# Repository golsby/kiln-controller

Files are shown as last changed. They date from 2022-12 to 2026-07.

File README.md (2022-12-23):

Kiln Controller
==========

Turns a Raspberry Pi into an inexpensive, web-enabled kiln controller.

## Features

  * easy to create new kiln schedules and edit / modify existing schedules
  * no limit to runtime - fire for days if you want
  * view status from multiple devices at once - computer, tablet etc
  * real-time firing cost estimate
  * NIST-linearized conversion for accurate K type thermocouple readings
  * supports PID parameters you tune to your kiln
  * monitors temperature in kiln after schedule has ended
  * api for starting and stopping at any point in a schedule
  * supports MAX31856 and MAX31855 thermocouple boards
  * support for K, J, N, R, S, T, E, or B type thermocouples
  * accurate simulation
  * support for shifting schedule when kiln cannot heat quickly enough
  * prevents integral wind-up when temperatures not near the set point
  * automatic restarts if there is a power outage or other event

**Run Kiln Schedule**

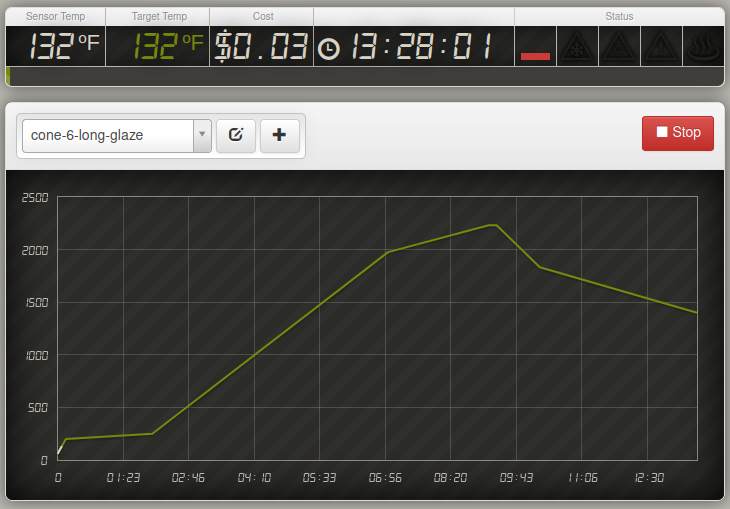
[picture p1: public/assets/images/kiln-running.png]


**Edit Kiln Schedule**



## Hardware

### Parts

| Image | Hardware | Description |
| ---| --- | --- |
|  | [Raspberry Pi](https://www.adafruit.com/category/105) | Virtually any Raspberry Pi will work since only a few GPIO pins are being used. |
|  | [MAX31855](https://www.adafruit.com/product/269) or [MAX31856](https://www.adafruit.com/product/3263) | Thermocouple breakout board |
|  | [K-Type Thermocouple](https://www.auberins.com/index.php?main_page=product_info&cPath=20_3&products_id=39) | Invest in a heavy duty, ceramic, k-type thermocouple designed for kilns |
|  | Breadboard | breadboard, ribbon cable, connector for pi's gpio pins & connecting wires |
|  | Solid State Relay | Zero crossing, make sure it can handle the max current of your kiln. Even if the kiln is 220V you can buy a single [3 Phase SSR](https://www.auberins.com/index.php?main_page=product_info&cPath=2_30&products_id=331). It's like having 3 SSRs in one.  Relays this big always require a heat sink. |
|  | Electric Kiln | There are many old electric kilns on the market that don't have digital controls. You can pick one up on the used market cheaply.  This controller will work with 110V or 220V (pick a proper SSR). My kiln is a Skutt KS-1018. |

### Schematic

The pi has three gpio pins connected to the MAX31855 chip. D0 is configured as an input and CS and CLK are outputs. The signal that controls the solid state relay starts as a gpio output which drives a transistor acting as a switch in front of it. This transistor provides 5V and plenty of current to control the ssr. Since only four gpio pins are in use, any pi can be used for this project. See the [config](https://github.com/jbruce12000/kiln-controller/blob/master/config.py) file for gpio pin configuration.

My controller plugs into the wall, and the kiln plugs into the controller. 

**WARNING** This project involves high voltages and high currents. Please make sure that anything you build conforms to local electrical codes and aligns with industry best practices.



*Note: I tried to power my ssr directly using a gpio pin, but it did not work. My ssr required 25ma to switch and rpi's gpio could only provide 16ma. YMMV.*

## Software 

### Raspberry PI OS

Download [Raspberry PI OS](https://www.raspberrypi.org/software/). Use Rasberry PI Imaging tool to install the OS on an SD card. Boot the OS, open a terminal and...

    $ sudo apt-get update
    $ sudo apt-get dist-upgrade
    $ sudo apt-get install python3-dev python3-virtualenv libevent-dev virtualenv
    $ git clone https://github.com/jbruce12000/kiln-controller
    $ cd kiln-controller
    $ virtualenv -p python3 venv
    $ source venv/bin/activate
    $ export CFLAGS=-fcommon
    $ pip3 install --upgrade setuptools
    $ pip3 install greenlet bottle gevent gevent-websocket

*Note: The above steps work on ubuntu if you prefer*

### Raspberry PI deployment

If you're done playing around with simulations and want to deploy the code on a Raspberry PI to control a kiln, you'll need to do this in addition to the stuff listed above:

    $ cd kiln-controller
    $ virtualenv -p python3 venv
    $ source venv/bin/activate
    $ export CFLAGS=-fcommon
    $ pip3 install -r requirements.txt

## Configuration

All parameters are defined in config.py, review/change to your mind's content.

You should change, test, and verify PID parameters in config.py.  Here is a [PID Tuning Guide](https://github.com/jbruce12000/kiln-controller/blob/master/docs/pid_tuning.md). There is also an [autotuner](https://github.com/jbruce12000/kiln-controller/blob/master/docs/ziegler_tuning.md). Be patient with tuning. No tuning is perfect across a wide temperature range.

You may want to change the configuration parameter **sensor_time_wait**. It's the duty cycle for the entire system.  It's set to two seconds by default which means that a decision is made every 2s about whether to turn on relay[s] and for how long. If you use mechanical relays, you may want to increase this. At 2s, my SSR switches 11,000 times in 13 hours.

## Usage

### Server Startup

    $ source venv/bin/activate; ./kiln-controller.py

### Autostart Server onBoot
If you want the server to autostart on boot, run the following command:

    $ /home/pi/kiln-controller/start-on-boot

### Client Access

Click http://127.0.0.1:8081 for local development or the IP
of your PI and the port defined in config.py (default 8081).

### Simulation

In config.py, set **simulate=True**. Start the server and select a profile and click Start. Simulations run at near real time.

### Watcher

If you're busy and do not want to sit around watching the web interface for problems, there is a watcher.py script which you can run on any machine in your local network or even on the raspberry pi which will watch the kiln-controller process to make sure it is running a schedule, and staying within a pre-defined temperature range. When things go bad, it sends messages to a slack channel you define. I have alerts set on my android phone for that specific slack channel. Here are detailed [instructions](https://github.com/jbruce12000/kiln-controller/blob/master/docs/watcher.md).

## License

This program is free software: you can redistribute it and/or modify
it under the terms of the GNU General Public License as published by
the Free Software Foundation, either version 3 of the License, or
(at your option) any later version.

This program is distributed in the hope that it will be useful,
but WITHOUT ANY WARRANTY; without even the implied warranty of
MERCHANTABILITY or FITNESS FOR A PARTICULAR PURPOSE.  See the
GNU General Public License for more details.

You should have received a copy of the GNU General Public License
along with this program.  If not, see <http://www.gnu.org/licenses/>.

## Support & Contact

Please use the issue tracker for project related issues.
If you're having trouble with hardware, I did too.  Here is a [troubleshooting guide](https://github.com/jbruce12000/kiln-controller/blob/master/docs/troubleshooting.md) I created for testing RPi gpio pins.

## Origin
This project was originally forked from https://github.com/apollo-ng/picoReflow but has diverged a large amount.

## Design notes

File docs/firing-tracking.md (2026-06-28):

# Firing Tracking & History — Design

Status: **in progress** (branch `firing-tracking`; round 2 on `merge-timeline`)
Author: Brian Gillespie
Last updated: 2026-06-28

## Round 2 (branch `merge-timeline`)

Brings the history detail to the **live, in-progress firing** and makes photos first-class:

- **Live unified detail.** `/status` now broadcasts `firing_id` (`ovenWatcher`); while a
  firing runs the dashboard shows the same detail view as history (annotated canvas graph +
  live event timeline + editable notes) for that firing, polling `/api/firings/<id>` every
  ~5 s. The flot graph is used only for idle profile preview/editing.
- **Segments behind Edit.** The live segment editor no longer auto-shows; an "Edit schedule"
  toggle reveals it (table-driven: tap a row to edit its target/hold via `/control`).
- **Photos as moments.** Photos taken during a firing carry the capture `runtime` (sent on
  upload), so they appear as 📷 markers on the graph and as their own rows in the timeline at
  the exact time slice (single source of truth in `metadata.photos`, not separate events).
  Click a marker/thumbnail → lightbox with the full image and an editable per-photo **note**.
- **Layout.** Timeline and notes stack vertically; the timeline grows to show every event
  (no inner scroll).
- **Printable report.** `report.html?id=<id>` renders a clean, paper-styled full report
  (graph, entire timeline, notes, all photos + captions); a Report link sits on the detail.

Backend: photo entries are `{file, runtime, note}`; `PATCH /api/firings/:id/photos/:name`
sets the note. **Writes to the active firing go through the live `FiringRecorder`** (it owns
`record.json` in memory) so the watcher's flushes can't clobber notes/photos edited mid-firing.

## Goal

Give the kiln controller a durable concept of a **firing**: capture every run as a
self-contained record (the planned schedule, the actual temperature log, a timeline of
what happened, and human-authored notes/results), and surface past firings in the
dashboard for review and annotation.

Today the system has **no concept of a completed firing**. Profiles persist as JSON;
everything else is ephemeral — the live time-series lives only in `ovenWatcher.last_log`
in memory and is wiped on Stop or client reconnect. There is a standing `FIXME` at
`lib/ovenWatcher.py:104` — *"need to save runs of schedules in near-real-time."* This
feature answers it.

## Scope & non-goals

In scope:
- A persistent, self-contained **firing record** per run, captured in near-real-time.
- A **controller identity** (GUID + human name) established from day one.
- A **History** view in the dashboard (list + detail with planned-vs-actual graph,
  event annotations, and editable metadata).
- A one-time **importer** that backfills past firings from `process.log` + existing CSVs.

Explicitly out of scope (deferred to the future **cloud/remote-access** project):
- Remote access from outside the LAN, auth, multi-tenant accounts.
- Syncing multiple controllers under one account.
- Cloud storage / offload of records or photos.

This design is **cloud-forward**, not cloud-coupled: records are self-contained bundles
and all access goes through a clean local `/api/firings` REST surface, so the future AWS
layer is a proxy in front of this — not a rewrite.

## Controller identity

Established now because it is cheap to add and expensive to retrofit once firing records
reference it.

- Stored in a **gitignored `controller.json`** at the repo root, alongside `resume.json`
  and `state.json` — per-device, survives `git pull`, never committed (so every tenant's
  device is globally unique).
- Auto-created on first startup if absent:
  ```json
  { "id": "f47ac10b-58cc-4372-a567-0e02b2c3d479", "name": "Studio Kiln" }
  ```
  - `id` — a UUIDv4. Globally unique across all tenants/devices. Immutable.
  - `name` — human-friendly label shown on the dashboard. Editable. Defaults to the
    machine hostname on first creation.
- Exposed read-only via the existing `/config` websocket (`controller_id`,
  `controller_name`). Renamed via a new `/api` action `set_controller_name`.
- Every firing record embeds `controller_id` so records remain attributable after they
  are someday synced/merged across controllers.

## The firing record — a self-contained bundle

One directory per firing under `storage/firings/`, parallel to `storage/profiles/`:

```
storage/firings/<id>/
  record.json      # summary + embedded profile snapshot + user metadata
  samples.ndjson   # actual firing log: one get_state() dict per line, appended live
  events.ndjson    # discrete event timeline, appended live
  photos/          # user-attached before/after images
```

`<id>` is the UTC start timestamp in a filesystem-safe form, e.g.
`2026-06-22T21-23-13Z`. A directory (not a single file) because a firing accrues
heterogeneous content over its life: the curve while it runs, then notes and photos added
days later.

### `record.json`

```jsonc
{
  "id": "2026-06-22T21-23-13Z",
  "controller_id": "f47ac10b-...",          // attribution for future multi-controller
  "schema_version": 1,

  // ---- summary (auto-computed; refreshed on segment change + finalize) ----
  "status": "completed",                     // running | completed | aborted | error
  "started_at": "2026-06-22T21:23:13Z",
  "ended_at":   "2026-06-23T05:01:40Z",
  "duration_s": 27507,
  "max_temp": 1465.0,
  "peak_target": 1466.0,
  "total_cost": 3.49,
  "currency_type": "$",
  "temp_scale": "f",
  "segment_count": 6,

  // ---- the PLAN: profile snapshot as run (embedded, never a reference) ----
  "profile": { "name": "...", "type": "profile", "data": [[0,100],...], "rth": [...] },

  // ---- user metadata (editable forever after) ----
  "metadata": {
    "title": "",
    "tags": [],                 // free-form: "full-fuse", "test", "oceanside-thin"
    "fields": {},               // arbitrary user key→value; domain-agnostic
    "outcome": {
      "rating": null,           // 1–5
      "summary": "",
      "defects": [],            // free-form chips: "devit", "bubbles", "cracked"
      "went_well": "",
      "went_wrong": ""
    },
    "photos": []                // refs into photos/, with optional before/after label
  }
}
```

Design choices:
- **Embed the profile, don't reference it.** Profiles get edited and deleted; a record
  that stores only `"profile": "cone06-fast"` is worthless once that profile changes. The
  bundle carries the schedule *as actually run*.
- **Metadata is generic.** A fixed core where it helps the UI render controls (rating,
  defects), and open-ended `tags`/`fields` so it fits any craft without domain lock-in.

### `samples.ndjson` — the actual firing log

One slim line per sample, appended as `ovenWatcher` produces it. NDJSON because it is
append-only and crash-safe: if the Pi loses power mid-firing, the record up to that instant
survives. Only the fields needed to graph the firing and to reconstruct an idealized curve
from it are persisted:

```json
{"runtime": 350.0, "temperature": 146.86, "target": 147.6, "heat": 1.0, "totaltime": 7800.0}
```

Everything constant or derived — profile name, `cost`, `kwh_rate`, `currency_type`, the
upcoming-`segments` array, `pidstats`, `resume_*` — lives once in `record.json` rather than
being duplicated on every line. `state` is omitted too: samples are only captured while the
oven is `RUNNING`, so run-state changes are recorded as discrete events in `events.ndjson`. Values are lightly rounded (temps to 0.01°, below
thermocouple resolution) to drop precision-noise. This keeps a long firing's log small.

Note this is a deliberate split from the live feed: the `/status` websocket still carries
the **full** `get_state()` (the live dashboard needs `segments`, `pidstats` for the tuning
view, etc.); only the persisted file is slimmed. The UI downsamples stored samples for
display via a `?resolution=` query param.

### `events.ndjson` — what actually happened

A low-volume stream of discrete events, each `{ts, type, runtime, detail}`, appended live.
These turn a temperature curve into a *narrative*. Example line:

```json
{"ts": "2026-06-27T21:02:04Z", "type": "segment_target_edit", "runtime": 638.0, "detail": {"segment": 2, "old": 1826.0, "new": 900.0}}
```

The event types (vocabulary lives in `firingStore.EV_*`) and where each is emitted:

| Event type | Emitted by | When |
|---|---|---|
| `started` | watcher | a fresh bundle opens on the first RUNNING sample |
| `completed` / `aborted` / `error` | watcher | the run leaves RUNNING (terminal status inferred from oven state) |
| `hold` / `hold_release` | `oven.set_manual_hold` | manual hold engaged / released (detail: `setpoint`) |
| `advance` | `oven.advance_segment` | user skipped to the next segment (detail: `from_segment`, `to_segment`) |
| `segment_target_edit` / `segment_hold_edit` | `oven.set_segment_target` / `set_segment_hold` | runtime edit (detail: `segment`, `old`, `new`) |
| `segment_transition` | watcher | segment/phase changed between samples (RAMP↔HOLD, seg N→N+1) |
| `power_interruption` + `resumed` | watcher | capture continued an interrupted run |

Two emission sites: **user-action** events fire at the oven method chokepoints (so any
caller — `/control` or `/api` — is covered), while **lifecycle/derived** events fire from the
watcher loop. Because events are written from both the watcher thread and the gevent control
greenlet, `events.ndjson` writes are guarded by a lock + closed-flag in `FiringRecorder`.

A manual `advance` is followed by a `segment_transition` for the boundary it caused — both
are kept (the advance records *why*, the transition records the actual phase context).

The `power_interruption`/`resumed` pair is the high-value case. A power loss/crash leaves the
bundle `running` (never finalized); a deliberate Stop leaves it `aborted`. On resume the
watcher continues the **same** bundle and emits `resumed` (with `from_status`), preceded by
`power_interruption` only when the bundle was `running` (a genuine interruption, not a
deliberate stop). The graph then shows the gap exactly where reality diverged from the plan.

## Capture mechanism

Hook `ovenWatcher`'s existing loop, which already assembles every state sample:
- On firing start (`record()`): create the bundle dir, write initial `record.json`
  (status `running`, embedded profile), open `samples.ndjson`/`events.ndjson`, emit a
  `started` event.
- Each loop iteration while running: append the sample line; refresh `record.json` summary
  on segment changes.
- On control actions / scheduler transitions: append the corresponding event.
- On terminal state (DONE / abort / error): finalize `record.json` (status, `ended_at`,
  summary stats), emit the terminal event.
- On resume of an interrupted run: re-open the existing bundle (matched via `resume.json`),
  emit `power_interruption` + `resumed`, continue appending.

Near-real-time (not finalize-at-end) because firings are long and the failure that matters
is the one that kills the controller mid-run.

## API surface — REST under `/api/firings`

REST (not the `/storage` websocket) because a firing's time-series is thousands of points.
This surface is exactly what the future AWS proxy fronts unchanged.

| Method & path | Purpose |
|---|---|
| `GET /api/firings` | list summaries only (cheap; no samples) |
| `GET /api/firings/:id` | full record + samples (`?resolution=` to downsample) + events |
| `PATCH /api/firings/:id` | edit the user-metadata block |
| `POST /api/firings/:id/photos` | attach a photo |
| `DELETE /api/firings/:id` | delete a firing (and its photos) |

## Dashboard

- New **History** view: a grid of firing cards (date, profile name, max temp, status
  badge, optional thumbnail).
- **Detail** page reuses the existing graph component in `picoreflow.js` (it already plots
  a planned curve + a live log) fed from `samples.ndjson` instead of the websocket, with
  **event annotations** (vertical markers: ⏸ hold, ⏭ advance, ⚡ power loss) and a textual
  timeline beside it, plus an editable metadata/notes/results panel.
- Controller **name** shown in the dashboard header; inline rename.

## Migration / backfill

`scripts/import_firings.py` reconstructs past firings from a pre-tracking `process.log`. The
old log's per-sample lines are rich (`temp/target/heat_on/heat_off/run_time/total_time`), so
backfilled firings carry real curves — not sparse points. The importer:

- splits the log into run-segments, dropping noise (0-sample false starts, thermocouple
  `Refusing to start`, service-restart fragments with no data);
- **stitches** consecutive same-profile segments within a time gap (`--gap-min`, default 60)
  into one firing — a single physical firing is often fragmented across many crash/restart
  segments;
- re-bases each sample's `runtime` to **elapsed wall-seconds from the firing start** (each
  fragment restarts `run_time` at 0, which would otherwise fold the curve back on itself),
  and turns the restart seams into `power_interruption`/`resumed` events;
- keeps firings with `>= --min-samples` (default 10), embeds the planned curve from the
  profiles dir when the name matches, infers status (`schedule ended` → completed, else the
  last fragment's end reason), and marks the record `imported: true`.

`--dry-run` prints the plan without writing. Bundles are written via
`firingStore.import_firing` (same schema as live capture). Metadata is left empty for the
user to fill in.

Run against the production log it produced 6 firings from ~49k log lines (e.g. a 10 h 1"
full fuse, an 18.7 h completed fuse, and one 29 h cast+anneal stitched from 10 fragments).
**These bundles live wherever the importer writes** (`--out`); to populate the production
device's history, run the importer there (or copy the bundles over) once the backend is
deployed, re-stamping `controller_id` to that device's identity.

## Storage footprint

All local on the Pi. `samples.ndjson` is a few MB per firing — years of firings fit easily.
Photos are the only growth risk; deletion is made easy and cloud offload is deferred to the
AWS phase.

## Implementation plan (phased)

1. **Controller identity** — *done.* `controller.json` load-or-create, exposed via
   `/config`, rename via `/api`, name shown in the dashboard header.
2. **Capture core** — *done.* Bundle writer (`lib/firingStore.py`); `ovenWatcher` streams
   `samples.ndjson` and writes/finalizes `record.json` on the RUNNING edges. Resume (crash
   or explicit Stop) continues the same bundle; a fresh start finalizes orphaned `running`
   bundles as `interrupted`. `duration_s` is firing-clock time (excludes stopped gaps).
   record.json summary is refreshed on segment change + finalize; between those, a crash
   leaves a truthful `running` status and the full `samples.ndjson` (summary recomputable).
3. **Event timeline** — *done.* `events.ndjson` with the event vocabulary above. User
   actions emit at the oven chokepoints; lifecycle/transition/`power_interruption`/`resumed`
   emit from the watcher. Thread-safe writes. Verified for every event type in the simulator,
   including crash-resume (→ `power_interruption`+`resumed`) vs Stop-resume (→ `resumed` only).
4. **Read API** — *done.* `GET /api/firings` (summaries, newest first) and
   `GET /api/firings/:id` (full record + events + samples, `?resolution=N` downsamples and
   always keeps the last point). Path-traversal-safe `:id`; unknown id → 404. Read helpers
   live in `firingStore` (`list_firings`/`get_firing`).
5. **History UI** — *done.* A History view in the dashboard (toggled from the header;
   `#history` deep-link): a list sorted by firing date, and a detail view with a
   planned-vs-actual Canvas graph (area-filled actual line, faint grid, hover crosshair),
   event pins + red interruption bands, a typed event timeline **bidirectionally linked** to
   the graph (select a row → mark it on the curve; click a pin → scroll to the row), and a
   read-only notes panel. Reuses the app's design tokens; all styles scoped under
   `#history_view`. Verified in-browser against the backfilled firings.
6. **Metadata editing** — *done.* Editable notes panel: title (acts as the firing's
   display name when set), rating, tags, "what happened", defects, saved via
   `PATCH /api/firings/:id`. Photo upload (`POST …/photos`, served by `GET …/photos/:name`,
   removed by `DELETE`), shown as a thumbnail grid. Delete a firing
   (`DELETE /api/firings/:id`, confirm-gated). Path-traversal-safe ids; uploads capped by a
   raised `MEMFILE_MAX`. `scripts/merge_firings.py` (see Migration) handles firings that were
   split across two profiles.
7. **Backfill importer** — *done* (pulled forward). `scripts/import_firings.py`; see
   Migration / backfill above. Used to seed real history for building the UI.

Each phase is independently shippable and verifiable in the simulator.
```

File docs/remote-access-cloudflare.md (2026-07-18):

# Remote access — Cloudflare Tunnel + Access

"See (and stop) the kiln from anywhere," without opening any inbound port on the
home network. This is the **read + control** remote-access path; it is not the future
multi-tenant platform (that would be a device-telemetry broker — see the end).

## What it is

```
Browser ──HTTPS──> Cloudflare edge ──(Access: Google SSO)──> Cloudflare Tunnel
                                                                   │  (outbound-only
                                                                   │   connection from
                                                                   ▼   the Pi — no port
                                                            cloudflared on Pi   forwarding)
                                                                   │
                                                                   ▼
                                                    kiln-controller @ localhost:80
```

- Public hostname: **https://kilns.bgillespie.art**
- The Pi runs **`cloudflared`** as a systemd service. It dials *out* to Cloudflare's
  edge and holds the connection open — there is **no inbound firewall/router config**,
  no static IP, no dynamic DNS.
- **Cloudflare Access** enforces **Google SSO** in front of the hostname. Only
  allowlisted Google accounts get through. This gate covers everything, including the
  live-status websocket and the remote **Stop** control (websockets carry the Access
  cookie automatically).
- WebSockets (`/status`, `/control`, `/config`, `/storage`) pass through the tunnel
  transparently — no app changes were needed.

## Current facts (as deployed)

| Thing | Value |
|---|---|
| Public hostname | `kilns.bgillespie.art` |
| Tunnel name | `kiln` |
| Tunnel UUID | `35f0b8e1-ccc2-42a7-ae99-327a5edb5004` |
| Pi service | `cloudflared.service` (systemd), independent of `kiln-controller.service` |
| Local origin | `http://localhost:80` |
| DNS | `bgillespie.art` DNS is hosted on **Cloudflare** (registrar is **Namecheap**; nameservers point at Cloudflare). CloudFront site + Google Workspace email records were migrated over and are **DNS-only / grey-cloud**; only `kilns.*` is proxied/orange. |
| Identity | Cloudflare Access application (self-hosted) for `kilns.bgillespie.art`, IdP = Google, Allow policy = an email allowlist |
| Access team domain | `bgillespie.cloudflareaccess.com` |

## Secrets — what is deliberately NOT in this repo

None of these are committed; they live on the Pi / in Cloudflare / in Google:

- `/home/brian/.cloudflared/cert.pem` — account/zone origin cert (used only for
  management commands: create/delete tunnel, route DNS).
- `/etc/cloudflared/<UUID>.json` — the tunnel credentials (used at runtime by the service).
- The **Google OAuth Client Secret** — entered only into the Cloudflare Access Google
  IdP config. Never paste it into chat, code, or docs.

## Operational notes

- **The tunnel is a separate service from the kiln.** Installing, restarting, or
  removing `cloudflared` does **not** touch `kiln-controller`, drop the contactor, or
  affect a firing. Conversely, restarting `kiln-controller` doesn't disturb the tunnel.
  All of this is **safe to do mid-firing**.
- **Static-asset deploys** (`public/**`) are unaffected — still just a `git pull`,
  reachable immediately through the tunnel on browser reload.
- Health checks (on the Pi):
  ```bash
  systemctl status cloudflared
  cloudflared tunnel info kiln          # shows edge connections
  journalctl -u cloudflared -n 50       # tunnel logs
  ```
- Verify the Access gate from anywhere (should be a 302 to `*.cloudflareaccess.com`,
  NOT the dashboard HTML):
  ```bash
  curl -sS -o /dev/null -D - https://kilns.bgillespie.art/ | grep -iE '^HTTP|^location'
  ```

## Reproduce on a fresh Pi

Assumes `bgillespie.art` DNS is already on Cloudflare (see "DNS" below if not).

1. **Install cloudflared.** The Pi is 32-bit (`armhf`, Raspbian Bullseye). Cloudflare's
   apt repo only ships amd64/arm64, so install the `armhf` `.deb` directly:
   ```bash
   cd /tmp
   curl -fsSL -o cloudflared.deb \
     https://github.com/cloudflare/cloudflared/releases/latest/download/cloudflared-linux-armhf.deb
   sudo dpkg -i cloudflared.deb
   cloudflared --version
   ```
   (On a 64-bit Pi OS you *can* use the apt repo / `arm64` `.deb` instead.)

2. **Authenticate** (interactive — opens a browser):
   ```bash
   cloudflared tunnel login       # authorize the bgillespie.art zone in the browser
   ```
   Writes `~/.cloudflared/cert.pem`. **Gotcha:** on a headless Pi this sometimes prints
   `error="Failed to fetch resource"` and the browser instead *downloads* `cert.pem`.
   If so, just place that file at `~/.cloudflared/cert.pem` yourself
   (e.g. `ssh pi 'cat > ~/.cloudflared/cert.pem' < ~/Downloads/cert.pem` then
   `chmod 600`).

3. **Create the tunnel:**
   ```bash
   cloudflared tunnel create kiln     # note the UUID + creds JSON path it prints
   ```

4. **Config + service.** Stage config and creds under `/etc/cloudflared/`:
   ```bash
   sudo mkdir -p /etc/cloudflared
   sudo cp ~/.cloudflared/<UUID>.json /etc/cloudflared/
   sudo tee /etc/cloudflared/config.yml >/dev/null <<'EOF'
   tunnel: <UUID>
   credentials-file: /etc/cloudflared/<UUID>.json

   ingress:
     - hostname: kilns.bgillespie.art
       service: http://localhost:80
     - service: http_status:404
   EOF
   cloudflared tunnel ingress validate
   sudo cloudflared service install
   sudo systemctl enable --now cloudflared
   cloudflared tunnel info kiln          # should show edge connections
   ```

5. **Configure Access FIRST, then route DNS.** Order matters: a routed hostname with no
   Access app is publicly open. So set up Access (next section) *before* step 6.

6. **Route DNS (go live):**
   ```bash
   cloudflared tunnel route dns kiln kilns.bgillespie.art
   ```
   Then verify the Access 302 (see Operational notes).

## Cloudflare Access + Google SSO (dashboard)

1. **Zero Trust** onboarding → pick a team name → `bgillespie.cloudflareaccess.com`
   (Free plan, up to 50 users).
2. **Google IdP:** create an OAuth "Web application" client in Google Cloud Console
   (APIs & Services → Credentials), with:
   - JavaScript origin: `https://bgillespie.cloudflareaccess.com`
   - Redirect URI: `https://bgillespie.cloudflareaccess.com/cdn-cgi/access/callback`
   Then Zero Trust → Settings → Authentication → add **Google**, paste the Client ID
   (App ID) + Client Secret, **Test** it.
3. **Access application:** Zero Trust → Access → Applications → **Add → Self-hosted**;
   hostname `kilns.bgillespie.art`; select **Google only** as the IdP; add an
   **Allow** policy with an **Emails** include list (the allowlist). Save.

## DNS notes (moving a domain to Cloudflare)

- Free-plan Cloudflare requires the hostname's **whole zone** to be on Cloudflare.
  Delegating only a subdomain (keeping the parent authoritative elsewhere) is an
  **Enterprise-only** feature — not available on Free/Pro/Business.
- When migrating `bgillespie.art` from Route 53: Cloudflare's importer set the apex to
  hardcoded CloudFront **A** records — wrong (those IPs rotate). Replace with a
  **CNAME at the apex** → `d5yhsqtcd4b6l.cloudfront.net`, **DNS-only** (Cloudflare
  flattens it and keeps it current). Copy MX / SPF / **DKIM** exactly (email breaks
  silently otherwise), and keep the `_…acm-validations.aws` CNAMEs so the CloudFront
  cert keeps auto-renewing. The importer skips those underscore records — add them by hand.

## Not this: the future platform

This gives *one* operator remote access to *this* kiln's existing dashboard. A
multi-tenant "others' kilns" platform is a different architecture (device-initiated
telemetry broker, e.g. AWS IoT Core, scale-to-zero) — intentionally out of scope here.

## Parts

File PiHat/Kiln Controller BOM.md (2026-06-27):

# Kiln Controller PiHat — Bill of Materials

Generated from `Kiln Controller.fzz` (Fritzing sketch). Of the 488 placements in the
sketch, 459 are wires, vias, ground symbols, and net/power labels (PCB artifacts); the
**29 real component placements** are listed below.

## Active / semiconductor

| Qty | Designators | Part | Value / Marking | Package |
|-----|---|---|---|---|
| 2 | IC1, IC2 | MAX31855K thermocouple-to-digital converter | "MAX31855K" | SOIC-8 (SO08-EIAJ) |
| 4 | U1, U2, U3, U4 | Sharp PC817 optocoupler | — | Sharp-PC817 (confirm DIP-4 vs SMD) |
| 2 | Q1, Q2 | BC847 NPN transistor | — | SOT-23 (SMD) |

## Passives

| Qty | Designators | Value | Rating | Package |
|-----|---|---|---|---|
| 3 | C1, C2, C4 | 100 nF (0.1 µF) | 35 V | 0805 |
| 1 | C3 | 10 nF | 35 V | 0805 |
| 1 | R1 | 47 kΩ | ±5%, 0.25 W | 0805 |

## LEDs (0805)

| Qty | Designators | Color |
|-----|---|---|
| 4 | DOOR, EMRG, RUN, SAFE | Green (570 nm) |
| 1 | HEAT | Red (633 nm) |

## Connectors

| Qty | Designators (net) | Part |
|-----|---|---|
| 9 | +5V, +5V, CTX, DOOR, EMRG, GND, HEAT, TC-PRI, TC-Safe | 2-position screw terminal, 0.1″ (100 mil) pitch |

## Boards / modules

| Qty | Ref | Part |
|-----|-----|---|
| 1 | "Arduino Metro Mini" | Adafruit #2590 (Metro Mini 328) — independent safety-watcher MCU |
| 1 | "Raspberry Pi 1" | Raspberry Pi 3 (RPI-3-V1.2) — host SBC the HAT plugs onto (not populated on this PCB) |

**Totals:** 2× MAX31855K, 4× PC817, 2× BC847, 5× capacitors, 1× resistor, 5× LEDs,
9× screw terminals, 1× Metro Mini, plus the host Pi.

## Notes / verify before ordering

1. **Only one resistor (R1, 47 kΩ) is placed.** A board with 5 LEDs, 4 optocouplers, and
   2 transistors would normally need LED current-limiting and transistor base resistors.
   Either the Fritzing sketch is incomplete or those resistors live off-board — confirm
   against the schematic.
2. **No 2×20 (40-pin) GPIO header** appears as a discrete part — the Pi is modeled as a
   whole board. A real HAT needs a 40-pin female header to seat on the Pi; add it to the
   assembly BoM.
3. **PC817 footprint** — the Sharp PC817 is THT DIP-4 by default but has an SMD variant;
   confirm which footprint the PCB actually uses.

## Net / function reference

| Net | Function |
|-----|---|
| +5V, GND | Power rails |
| HEAT | Heating-element solid-state relay drive (red indicator LED) |
| CTX | Contactor |
| EMRG | Emergency shutoff input |
| DOOR | Door switch input |
| TC-PRI | Primary thermocouple (main control sensor) |
| TC-Safe | Safety thermocouple (independent watcher sensor) |
| RUN, SAFE | Status indicator LEDs |

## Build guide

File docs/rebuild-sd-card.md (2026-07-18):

# Rebuilding the Raspberry Pi SD card (Bookworm)

How to reconstruct the production kiln controller on a fresh SD card. Written
after a from-scratch rebuild on **2026-07-18** (Pi 3 B, Raspberry Pi OS Bookworm).
The scripted part is [`scripts/kiln-firstsetup.sh`](../scripts/kiln-firstsetup.sh);
remote access is in [`remote-access-cloudflare.md`](remote-access-cloudflare.md).

## Gotchas that will bite you (read first)

- **"Raspberry Pi OS Lite (Legacy)" is now Bookworm, not Bullseye.** Debian's
  *oldstable* rolled forward. Bookworm changes two things that broke the old
  headless recipe:
  - The FAT boot partition mounts at **`/boot/firmware/`**, not `/boot/`. Staged
    files (setup script, `kiln_authorized_keys`) land there.
  - The network stack is **NetworkManager**, so a `wpa_supplicant.conf` dropped on
    the boot partition is **ignored**. Configure Wi-Fi via Raspberry Pi Imager's
    customization, or on the Pi with `nmcli` / `raspi-config nonint do_wifi_country US`.
- **Power the Pi from its own 5V/2.5A+ supply — never a Mac/PC USB port.** A Pi 3
  browns out on ~0.9–1.5A; add a monitor and it reboot-loops. That loop looked
  like a networking failure but was undervoltage. Boot **headless** (no HDMI).
- **The app needs I2C + SPI enabled or it crash-loops.** `lib/arduinoWatcher.py`
  opens `/dev/i2c-1` at construction (uncaught `FileNotFoundError` if absent), and
  the MAX31855 uses SPI. `kiln-firstsetup.sh` enables both, but they require a
  **reboot** to take effect.
- **Raspberry Pi OS Lite has no `curl`** preinstalled (needed for cloudflared).
  The setup script installs it.
- **No thermocouple wired → a flat phantom ~1500°F.** Not a fault. Verify ~room
  temp once the sensor is on GPIO CS=27/CLK=22/DO=17, before any real firing.

## Procedure

1. **Flash** Raspberry Pi OS Lite (Legacy, 32-bit) to the card. Easiest is the
   Raspberry Pi Imager with OS customization set: hostname `kiln`, user `brian`
   (+ password), your SSH public key, Wi-Fi SSID + **country US**, timezone.
   (Imager configures Wi-Fi correctly for NetworkManager; the manual
   `wpa_supplicant.conf` route does not.)
2. **Boot headless** on a proper 2.5A+ supply. Find it: `ssh brian@kiln.local`
   (or scan the LAN for a `b8:27:eb` / `dc:a6:32` MAC).
3. **Run setup:** `bash scripts/kiln-firstsetup.sh` (or clone the repo first and
   run it from there). Add `BRANCH=firing-tracking` to deploy the preview branch.
4. **Reboot** (`sudo reboot`) to apply I2C/SPI + hostname. Then verify:
   `curl -sS -o /dev/null -w '%{http_code}\n' http://localhost/` → `200`.
5. **PagerDuty** (optional): put the Events API v2 key in a gitignored `.env`:
   `echo 'PAGERDUTY_ROUTING_KEY=...' >> ~/kiln-controller/.env && chmod 600 ~/kiln-controller/.env`,
   then restart the service.
6. **Cloudflare tunnel:** follow [`remote-access-cloudflare.md`](remote-access-cloudflare.md).
   The `~/.cloudflared/cert.pem` (account/zone cert) is reusable across rebuilds;
   only the tunnel **credentials JSON** is card-specific, so delete the orphaned
   tunnel and create a fresh one, then `route dns --overwrite-dns`.

## Faster path: restore an image

A full `dd` clone of a known-good card restores an identical system in minutes
(reused host keys, Wi-Fi profile, tunnel creds — no re-setup). It also contains
**every secret**, so store it encrypted. Restore: `gzip -dc kiln-<date>.img.gz |
sudo dd of=/dev/rdiskN bs=4m` onto a same-or-larger card. This complements, but
does not replace, the config-in-git path above (images go stale).

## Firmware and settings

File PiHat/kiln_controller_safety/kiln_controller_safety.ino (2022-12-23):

// Over-temp Safety System

// Include the Wire library for I2C
#include <Wire.h>
#include <SPI.h>
#include <avr/wdt.h>
#include "Adafruit_MAX31855.h"

enum MessageType
{
  SetMaxTemp,
  GetCurrentTemp,
  OK,
  ERROR,
  OVER_TEMP_ALARM,
  RESET,
  GetMaxTemp
};

struct msg
{
  unsigned int type;
  double value;
};

// Pin Configuration
#define MAXDO 2
#define MAXCS 3
#define MAXCLK 4
#define ENABLE_PIN 12

msg msg_received;
msg output_message;
int error_state = 0;

double temp_stack[50];
int temp_stack_index = 0;
int temp_stack_max = 50;

double max_temp = 1000.0; // degrees C
bool over_temp_alarm = false;
double current_temp = 1234.0; // degrees C
double internal_temp = 0.0;
Adafruit_MAX31855 thermocouple(MAXCLK, MAXCS, MAXDO);
char log_msg[200];

void setup()
{
  for (int i = 0; i < temp_stack_max; i++)
  {
    temp_stack[i] = 0.0;
  }
  // Join I2C bus as slave with address 8
  Wire.begin(0x8);

  // Call receiveEvent when data received
  Wire.onReceive(onDataReceived);
  Wire.onRequest(onDataRequested);

  // Setup MAX31855
  Serial.begin(9600);

  Serial.println("MAX31855 setting up...");
  // wait for MAX chip to stabilize
  delay(500);
  Serial.print("Initializing sensor...");
  while (1)
  {
    if (thermocouple.begin())
    {
      break;
    }
    else
    {
      Serial.print(".");
      delay(10);
    }
  }

  // OPTIONAL: Can configure fault checks as desired (default is ALL)
  // Multiple checks can be logically OR'd together.
  // thermocouple.setFaultChecks(MAX31855_FAULT_OPEN | MAX31855_FAULT_SHORT_VCC);  // short to GND fault is ignored

  Serial.println(" done.");

  // Setup output pin
  pinMode(ENABLE_PIN, OUTPUT);
  digitalWrite(ENABLE_PIN, LOW);
}

void reboot()
{
  wdt_disable();
  wdt_enable(WDTO_15MS);
  while (1)
  {
  }
}

// Function that executes whenever data is received from master
void onDataReceived(int numBytes)
{
  // Serial.print("Received event with bytes: ");
  // Serial.println(numBytes);
  // Serial.print("Hoping for bytes: ");
  // Serial.println(sizeof(msg));

  if (Wire.available())
  { // loop through all but the last
    // Serial.println("  receiving...");
    Wire.readBytes((byte *)&msg_received, sizeof(msg_received));

    char msg[100];
    sprintf(msg, "Message %d received.", msg_received.type);
    Serial.println(msg);

    if (msg_received.type == MessageType::SetMaxTemp)
    {
      max_temp = msg_received.value;
      Serial.println("Setting max temp to:");
      Serial.println(max_temp);
    }
    if (msg_received.type == MessageType::RESET)
    {
      reboot();
    }
  }
  // Serial.println("   done...");
}

// Function is called when master requests data from us.
void onDataRequested()
{
  if (over_temp_alarm)
  {
    output_message.type = MessageType::OVER_TEMP_ALARM;
    output_message.value = ComputeCurrentTemp();
  }
  else
  {
    switch (msg_received.type)
    {
    case MessageType::SetMaxTemp:
      output_message.type = MessageType::OK;
      output_message.value = max_temp;
      break;
    case MessageType::GetMaxTemp:
      output_message.type = MessageType::GetMaxTemp;
      output_message.value = max_temp;
      break;
    case MessageType::GetCurrentTemp:
    {
      double currentTemp = ComputeCurrentTemp();
      if (isnan(currentTemp))
      {
        output_message.type = MessageType::ERROR;
        output_message.value = error_state;
      }
      else
      {
        output_message.type = MessageType::GetCurrentTemp;
        output_message.value = currentTemp;
      }
      break;
    }
    default:
      output_message.type = MessageType::ERROR;
      output_message.value = 0;
      break;
    }
  }
  Wire.write((byte *)&output_message, sizeof(output_message));
}

double ComputeCurrentTemp()
{
  double value = 0.0;
  int valid_value_count = 0;
  for (int i = 0; i < temp_stack_max; i++)
  {
    if (isnan(temp_stack[i]))
      continue;

    value += temp_stack[i];
    valid_value_count++;
  }

  if (valid_value_count == 0)
  {
    // Serial.println("    ComputeCurrentTemp: INVALID");
    return 0xFFFFFFFF;
  }

  double computedTemp = value / valid_value_count;
  char sCurrentTemp[20];
  char msg[200];
  dtostrf(computedTemp, 7, 1, sCurrentTemp);
  sprintf(msg, "    ComputeCurrentTemp %s from %d ", sCurrentTemp, valid_value_count);
  // Serial.println(msg);
  return computedTemp;
}

void append_temp(double value)
{
  temp_stack[temp_stack_index++] = value;
  if (temp_stack_index >= temp_stack_max)
  {
    temp_stack_index = 0;
  }
}

int measureTemp()
{
  internal_temp = thermocouple.readInternal();
  current_temp = thermocouple.readCelsius();
  uint8_t e = 0;
  // sprintf(sError, "UNINIT");

  append_temp(current_temp);

  if (isnan(current_temp))
  {
    // Serial.println("Thermocouple fault(s) detected!");
    e = thermocouple.readError();
    if (e & MAX31855_FAULT_OPEN)
    {
      // Serial.println("FAULT: Thermocouple is open - no connections.");
      error_state = MAX31855_FAULT_OPEN;
      // sprintf(sError, "OPEN");
    }
    else if (e & MAX31855_FAULT_SHORT_GND)
    {
      // Serial.println("FAULT: Thermocouple is short-circuited to GND.");
      error_state = MAX31855_FAULT_SHORT_GND;
      // sprintf(sError, "SHORT -> GND");
    }
    else if (e & MAX31855_FAULT_SHORT_VCC)
    {
      // Serial.println("FAULT: Thermocouple is short-circuited to VCC.");
      error_state = MAX31855_FAULT_SHORT_VCC;
      // sprintf(sError, "SHORT -> VCC");
    }
    else
    {
      // Serial.println("FAULT: UNKNOWN");
      error_state = 99;
      // sprintf(sError, "ERR UNKNOWN %d", 99);
    }
  }
  else
  {
    error_state = 0;
    // sprintf(sError, "OK");
  }

  return error_state;
}

void loop()
{
  // char sCurrentTemp[20], sMaxTemp[20], sInternalTemp[20], sError[20];
  int error_state = measureTemp();

  double ct = ComputeCurrentTemp();

  if (isnan(ct))
  {
    Serial.println("Temp NaN");
    digitalWrite(ENABLE_PIN, LOW);
  }
  else
  {
    if (ct < max_temp && !over_temp_alarm)
    {
      // Serial.println("Temp GOOD");
      digitalWrite(ENABLE_PIN, HIGH);
    }
    else
    {
      Serial.println("Temp OVER");
      digitalWrite(ENABLE_PIN, LOW);
      over_temp_alarm = true;
    }
  }
  // dtostrf(current_temp, 7, 1, sCurrentTemp);
  // dtostrf(max_temp, 7, 1, sMaxTemp);
  // dtostrf(internal_temp, 7, 1, sInternalTemp);
  // sprintf(log_msg, "Thermocouple: %s | Max: %s | Internal: %s | State: %s", sCurrentTemp, sMaxTemp, sInternalTemp, sError);
  // Serial.println(log_msg);
  delay(10);
}

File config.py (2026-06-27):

import logging
import os
import loadenv  # loads .env into os.environ (no-op if .env is absent)

# uncomment this if using MAX-31856
#from lib.max31856 import MAX31856

########################################################################
#
#   General options

# DEBUG (development) vs production. Set KILN_DEBUG=true in a local,
# gitignored .env file to run in development mode (simulated kiln,
# unprivileged port, accelerated simulation). Production has no .env, so
# DEBUG is False and the real-kiln defaults below apply.
DEBUG = os.environ.get("KILN_DEBUG", "false").strip().lower() in ("1", "true", "yes", "on")

### Logging
log_level = logging.INFO
log_format = '%(asctime)s %(levelname)s %(name)s: %(message)s'

### Server
# port 80 needs root in production; use an unprivileged port in development
listening_port = 8080 if DEBUG else 80
listening_ip = "0.0.0.0"

########################################################################
# Cost Information
#
# This is used to calculate a cost estimate before a run. It's also used
# to produce the actual cost during a run. My kiln has three
# elements that when my switches are set to high, consume 9460 watts.

kwh_rate        = 0.1319  # cost per kilowatt hour per currency_type to calculate cost to run job
kw_elements     = 9.460 # if the kiln elements are on, the wattage in kilowatts
currency_type   = "$"   # Currency Symbol to show when calculating cost to run job

########################################################################
#
#   GPIO Setup (BCM SoC Numbering Schema)
#
#   Check the RasPi docs to see where these GPIOs are
#   connected on the P1 header for your board type/rev.
#   These were tested on a Pi B Rev2 but of course you
#   can use whichever GPIO you prefer/have available.

### Outputs
gpio_heat = 11  # Switches zero-cross solid-state-relay
gpio_contactor = 9
gpio_arduino_reset = 10

### Thermocouple Adapter selection:
#   max31855 - bitbang SPI interface
#   max31856 - bitbang SPI interface. must specify thermocouple_type.
max31855 = 1
max31856 = 0
# see lib/max31856.py for other thermocouple_type, only applies to max31856
# uncomment this if using MAX-31856
#thermocouple_type = MAX31856.MAX31856_S_TYPE

### Thermocouple Connection (using bitbang interfaces)
gpio_sensor_cs = 27
gpio_sensor_clock = 22
gpio_sensor_data = 17
gpio_sensor_di = 10 # only used with max31856

########################################################################
#
# duty cycle of the entire system in seconds
# 
# Every N seconds a decision is made about switching the relay[s] 
# on & off and for how long. The thermocouple is read 
# temperature_average_samples times during and the average value is used.
sensor_time_wait = 2
time_log_interval = 30 # seconds


########################################################################
#
#   PID parameters
#
# These parameters control kiln temperature change. These settings work
# well with the simulated oven. You must tune them to work well with 
# your specific kiln. Note that the integral pid_ki is
# inverted so that a smaller number means more integral action.
pid_kp = 20   # Proportional 25,200,200
pid_ki = 50   # Integral
pid_kd = 100    # Derivative


########################################################################
#
# Initial heating and Integral Windup
#
# this setting is deprecated and is no longer used. this happens by
# default and is the expected behavior.
stop_integral_windup = True

########################################################################
#
#   Simulation parameters
# simulate the kiln in development; drive the real hardware in production
simulate = DEBUG
# Speed up a simulated run by this factor so you don't watch it in real
# time. 1 = real speed, 10 = ten times faster, etc. Only affects
# simulations; the real kiln always runs at 1. Must be > 0. Override
# locally with KILN_SIM_SPEEDUP in .env.
sim_speedup = float(os.environ.get("KILN_SIM_SPEEDUP", "60" if DEBUG else "1"))
sim_t_env      = 60.0   # deg C
sim_c_heat     = 500.0  # J/K  heat capacity of heat element
sim_c_oven     = 5000.0 # J/K  heat capacity of oven
sim_p_heat     = 5450.0 # W    heating power of oven
sim_R_o_nocool = 0.5   # K/W  thermal resistance oven -> environment
sim_R_o_cool   = 0.05   # K/W  " with cooling
sim_R_ho_noair = 0.1    # K/W  thermal resistance heat element -> oven
sim_R_ho_air   = 0.05   # K/W  " with internal air circulation


########################################################################
#
#   Time and Temperature parameters
#
# If you change the temp_scale, all settings in this file are assumed to
# be in that scale.

temp_scale          = "f" # c = Celsius | f = Fahrenheit - Unit to display
time_scale_slope    = "h" # s = Seconds | m = Minutes | h = Hours - Slope displayed in temp_scale per time_scale_slope
time_scale_profile  = "m" # s = Seconds | m = Minutes | h = Hours - Enter and view target time in time_scale_profile
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

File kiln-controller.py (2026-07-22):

#!/usr/bin/env python

import os
import sys
import logging
from logging.handlers import RotatingFileHandler
import json

# load .env before importing gevent so settings like PURE_PYTHON take effect
import loadenv

import bottle
import time
import gevent
#from bottle import post, get
from gevent.pywsgi import WSGIServer
from geventwebsocket.handler import WebSocketHandler
from geventwebsocket import WebSocketError
from scripts.schedule_converter import rth_to_segments, segments_to_points

try:
    sys.dont_write_bytecode = True
    import config
    sys.dont_write_bytecode = False
except:
    print ("Could not import config file.")
    print ("Copy config.py.EXAMPLE to config.py and adapt it for your setup.")
    exit(1)
    
logfile = os.path.join(os.path.dirname(__file__), 'process.log')

# my_handler = RotatingFileHandler(
#     logfile, 
#     mode='a', 
#     maxBytes=20*1024*1024,
#     backupCount=2, 
#     encoding=None, 
#     delay=False
# )
logging.basicConfig(
    filename=logfile,
    filemode='a',
    level=config.log_level, 
    format=config.log_format,
    #handlers = [my_handler]
)
log = logging.getLogger("kiln-controller")
log.info("Starting kiln controller")

script_dir = os.path.dirname(os.path.realpath(__file__))
sys.path.insert(0, script_dir + '/lib/')
profile_path = config.kiln_profiles_directory

from oven import SimulatedOven, RealOven, Profile
from ovenWatcher import OvenWatcher
import identity
import firingStore

# controller identity (GUID + human name); auto-created on first run
controller = identity.load_or_create(config.controller_state_file)

app = bottle.Bottle()
# allow multi-MB photo uploads (default cap is ~100KB and would truncate them)
bottle.BaseRequest.MEMFILE_MAX = 20 * 1024 * 1024

if config.simulate == True:
    log.info("this is a simulation")
    oven = SimulatedOven()
else:
    log.info("this is a real kiln")
    oven = RealOven()
ovenWatcher = OvenWatcher(oven)
# this ovenwatcher is used in the oven class for restarts
oven.set_ovenwatcher(ovenWatcher)

@app.route('/')
def index():
    return bottle.redirect('/kiln/index.html')

@app.get('/api/stats')
def handle_api():
    log.debug("/api/stats command received")
    if hasattr(oven,'pid'):
        if hasattr(oven.pid,'pidstats'):
            return json.dumps(oven.pid.pidstats)


def _io(fn, *args):
    '''Run a blocking filesystem call in gevent's threadpool so a large
    firing-history read/write doesn't stall the web event loop. The control and
    watcher run on separate OS threads and are unaffected either way; this keeps
    the *web* server responsive (websockets, other requests) during big reads.'''
    return gevent.get_hub().threadpool.apply(fn, args)


@app.get('/api/firings')
def handle_list_firings():
    '''Lightweight history listing (summaries only, newest first).'''
    bottle.response.content_type = 'application/json'
    return json.dumps(_io(firingStore.list_firings, config.firings_directory))


@app.get('/api/firings/<fid>')
def handle_get_firing(fid):
    '''Full record + events + samples for one firing. ?resolution=N caps the
    number of sample points returned (for graphing); ?samples=0 skips the
    (large) samples entirely — the live view uses that and gets its curve from
    the /status websocket stream instead.'''
    bottle.response.content_type = 'application/json'
    resolution = bottle.request.query.get('resolution')
    try:
        resolution = int(resolution) if resolution else None
    except ValueError:
        resolution = None
    include_samples = bottle.request.query.get('samples') != '0'
    data = _io(firingStore.get_firing, config.firings_directory, fid, resolution, include_samples)
    if data is None:
        bottle.response.status = 404
        return json.dumps({"error": "firing not found"})
    return json.dumps(data)


def _live_recorder(fid):
    '''Return the active FiringRecorder if `fid` is the firing currently being
    recorded, else None. Edits to a live firing must go through it (it owns
    record.json in memory and re-flushes it) or the watcher's next flush would
    clobber them.'''
    rec = getattr(ovenWatcher, 'firing', None)
    return rec if (rec is not None and rec.id == fid) else None


@app.route('/api/firings/<fid>', method='PATCH')
def handle_update_firing(fid):
    '''Edit a firing's user metadata (title, tags, rating, summary, defects,
    primary_photo).'''
    bottle.response.content_type = 'application/json'
    patch = bottle.request.json or {}
    live = _live_recorder(fid)
    meta = live.update_metadata(patch) if live else firingStore.update_metadata(config.firings_directory, fid, patch)
    if meta is None:
        bottle.response.status = 404
        return json.dumps({"error": "firing not found"})
    return json.dumps({"success": True, "metadata": meta})


@app.route('/api/firings/<fid>', method='DELETE')
def handle_delete_firing(fid):
    bottle.response.content_type = 'application/json'
    if _live_recorder(fid) is not None:
        bottle.response.status = 409
        return json.dumps({"error": "cannot delete a firing while it is running"})
    if not _io(firingStore.delete_firing, config.firings_directory, fid):
        bottle.response.status = 404
        return json.dumps({"error": "firing not found"})
    return json.dumps({"success": True})


@app.route('/api/firings/<fid>/photos', method='POST')
def handle_add_photo(fid):
    bottle.response.content_type = 'application/json'
    upload = bottle.request.files.get('photo')
    if upload is None:
        bottle.response.status = 400
        return json.dumps({"error": "no photo in request"})
    # optional capture time (firing-clock seconds) sent when shooting during a run
    runtime = None
    rt = bottle.request.forms.get('runtime')
    if rt not in (None, ""):
        try:
            runtime = float(rt)
        except (TypeError, ValueError):
            runtime = None
    live = _live_recorder(fid)
    name = _io(live.add_photo, upload, runtime) if live else \
        _io(firingStore.add_photo, config.firings_directory, fid, upload, runtime)
    if name is None:
        bottle.response.status = 400
        return json.dumps({"error": "unsupported image type or unknown firing"})
    return json.dumps({"success": True, "file": name})


@app.route('/api/firings/<fid>/photos/<name>', method='PATCH')
def handle_update_photo(fid, name):
    '''Set a photo's note / placement (runtime).'''
    bottle.response.content_type = 'application/json'
    patch = bottle.request.json or {}
    live = _live_recorder(fid)
    p = live.update_photo(name, patch) if live else \
        firingStore.update_photo(config.firings_directory, fid, name, patch)
    if p is None:
        bottle.response.status = 404
        return json.dumps({"error": "photo not found"})
    return json.dumps({"success": True, "photo": p})
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

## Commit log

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2022-09-08 More fixes to URL; enable real runs
    [config.py]
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2026-06-23 Add Clear-profile button + simulator/dev-environment tooling
    Phase 1 (UI):
    - Add a "Clear" button that wipes the loaded profile and live trace
    from the graph and resets the display. Hidden while RUNNING.
    - New CLEAR control-socket command drops ovenWatcher.last_profile/
    last_log so reconnecting clients don't reload a stale run.
    - Fix get_profiles(): it called json.loads() on a file object and
    appended twice, throwing and leaving the profile list empty. Now
    loads each .json once and skips/logs unreadable files.
    Simulator support (so a run can be tested off the Pi):
    - SimulatedOven honors a sim_speedup factor: shorten the per-step
    sleep and scale runtime so the profile, physics, and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
    [config.py, kiln-controller.py, loadenv.py]
2026-06-24 Phase 3: rate-paced control loop (SegmentScheduler)
    Replace the setpoint-tracking + "freeze the clock to catch up" control
    model with a rate-paced scheduler driven by the unified segment model.
    - SegmentScheduler (RAMP/HOLD/DONE): advances the setpoint at each
    segment's programmed rate, clamped so it never leads the actual kiln
    temperature by more than rate_tracking_window and never moves backward.
    A lagging kiln just extends the ramp - it is never driven past the
    rate to catch up. A hold counts down only while within hold_tolerance
    of target, so a soak is a true time-at-temperature. fast_forward()
    positions the schedule for restart/skip-ahead.
    - Oven: run_profile builds the sch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
    [config.py]
2026-06-24 Make accelerated simulation faithful to the real kiln
    At high sim_speedup the simulation diverged from real-kiln behavior
    because time was scaled via wall-clock. Drive simulated time
    deterministically and feed the controller a consistent timestep.
    - SimulatedOven.update_runtime: advance runtime by one time_step per
    control-loop iteration, in lockstep with the physics, instead of
    wall-clock * multiplier. No drift at any speed; runtime_multiplier
    now only sets the real sleep between iterations. Base Oven keeps
    pure wall-clock for the real kiln.
    - PID.compute: accept the control timestep and use it for the integral
    and derivative terms instead of measuring wall-clock. Previously, at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
2026-06-24 Phase 4: dynamic runtime estimate, retire dead catch-up config
    - SegmentScheduler.remaining_seconds(): nominal time left from the
    current setpoint/phase to the end of the schedule.
    - Oven.update_target_temp sets totaltime = runtime + remaining each
    tick, so the progress bar and ETA stay sensible (and never exceed
    100% / go negative) even when segments extend because the kiln lags.
    The existing picoreflow.js math works unchanged with this.
    - Remove the now-unused kiln_must_catch_up and kiln_catchup_window
    settings from config.py (replaced by the rate-paced scheduler).
    [config.py]
2026-06-24 Phase 6: manual Hold/Resume and Advance controls
    - SegmentScheduler.manual_hold: when set, advance() freezes the
    setpoint (no ramp progress, no soak countdown) until resumed - a
    pure pause/resume.
    - SegmentScheduler.skip_segment(): Advance keeps the current setpoint,
    drops the rest of the current segment, and begins the next segment's
    ramp from where the kiln is (no temperature jump). Clears any manual
    hold; ends the schedule on the last segment.
    - Oven.set_manual_hold()/advance_segment(); get_state reports
    manual_hold. /control gains HOLD, RESUME, ADVANCE commands.
    - UI: Hold (orange) <-> Resume (blue, distinct from the green Start)
    toggle and an Advance button, shown while RU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
    [kiln-controller.py]
2026-06-24 Phase 8: runtime segment editing (target + hold) with safety gate
    Adjust a running firing's segments without touching the saved profile.
    - SegmentScheduler.set_segment_target/set_segment_hold: future segments
    update in place; the active segment re-aims at runtime without a
    setpoint jump (mid-ramp reverses direction if needed; during a hold it
    ramps to the new target then serves the remaining/total soak).
    - Oven.set_segment_target/set_segment_hold with an emergency_shutoff_temp
    guard; get_state publishes the live segments and start_temp. /control
    gains SET_SEGMENT_TARGET and SET_SEGMENT_HOLD.
    UI:
    - A Segments table appears below the graph while RUNNING (rate, editable
    target, ed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
    [kiln-controller.py]
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2026-06-24 Clear button: keep the selected profile, wipe only the run trace
    Previously Clear emptied the ideal (green) curve and deselected the
    dropdown too. Now it clears only the live (red) run trace and resets the
    readouts, leaving the selected profile loaded so it can be re-run.
    OvenWatcher.clear() keeps last_profile (only drops last_log), so a
    reconnecting browser still sees the profile curve without the old run.
2026-06-24 Phase 9: kiln watcher resilience and idle handling
    A watcher thermocouple fault used to abort the firing instantly and spam
    errors while idle. Make the watcher recover gracefully without killing a
    firing.
    - ovenWatcher: a sensor/comm fault no longer aborts. After a short
    debounce (watcher_error_threshold consecutive errors) it tries to reset
    the watcher (resetArduino + re-send max temp); if that doesn't recover
    it, it raises an alarm, keeps retrying the reset periodically, and the
    firing continues on the main thermocouple. A good read clears the
    alarm. A genuine OVER_TEMP_ALARM still aborts (real safety event).
    - Faults are ignored while idle; the watcher is initialized once at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
    [config.py, kiln-controller.py]
2026-06-24 Add PagerDuty alerting for kiln faults (Events API v2, free plan)
    Notify the operator's phone when something goes wrong, via PagerDuty's
    Events API v2 (works on the free plan; notifies the PagerDuty mobile app).
    - notifier.py: fire-and-forget pagerduty_event(action, dedup_key, ...)
    using urllib (no new dependency) on a daemon thread so a slow network
    never blocks the control/watcher loops. No-op unless a routing key is
    configured.
    - Watcher alarm raises a PagerDuty incident (send_alert) and resolves it
    automatically when the watcher recovers or the kiln goes idle
    (dedup_key kiln-watcher).
    - Any firing abort (temp too high, lost thermocouple, over-temp, ...)
    triggers an incident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
    [config.py, notifier.py]
2026-06-26 Modernize the web UI
    Replace the legacy status panel with a clean, responsive dashboard.
    - Big sensor temperature with a heating glow/pill; Target beneath. The
    meaningless Cost field is gone.
    - iOS-style radial progress ring showing percent through the firing with
    the completion time in the center ("done 3:45 PM").
    - Status card shows the run state, the current segment, and both the
    ramp-reaches-temp ETA and the hold-ends ETA as fixed clock times
    ("eta 11:35, hold until 11:55"). All ETAs anchor to the run's start
    clock so they don't drift when the simulator runs fast.
    - Graph x-axis is wall-clock time, with ticks snapped to clean
    quarter/hour boundaries.
    - Run controls (Start /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
2026-06-26 Polish UI: native profile dropdown, mobile layout, axis labels
    - Replace the select2 profile dropdown with a styled native <select>:
    on iOS it opens the native picker instead of popping the keyboard,
    and it matches the modern styling. The selector is a flex row so the
    edit/+ buttons stay to the right of the dropdown at any width.
    - Mobile graph: shorter clock labels (drop ":00" on the hour) and fewer
    ticks so they don't crowd/overlap; ticks stay on clean boundaries.
    - Segment editor table scrolls horizontally instead of being clipped,
    and compacts on small screens.
    - Drop the "run completed" popup on normal completion / Stop; only
    errors notify now.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
2026-06-27 Add manual resume of a stopped firing + sim set_temp debug hook
    Resume:
    - Continuously snapshot the running firing (profile, runtime, cost, and
    the scheduler's exact position: segment/phase/setpoint/hold) to
    resume.json, independent of the automatic_restarts flag. Kept on
    Stop/error; removed on natural completion or Clear; reloaded on startup.
    - Start dialog shows a "Resume previous firing — <profile> at <time>"
    checkbox when a snapshot exists. Resuming restores the scheduler's
    exact stopped position (SegmentScheduler.restore) rather than
    fast-forwarding by elapsed time, which overshot when the kiln had
    lagged. Restores cost; the red live trace continues. Persists across a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
    [config.py, kiln-controller.py]
2026-06-27 Surface watcher I2C/bus faults; add /api resume
    - ovenWatcher._poll_watcher: treat ANY getCurrentTemp() failure as a
    watcher fault, not just KilnWatcherError. A raw I2C/bus error
    (OSError, e.g. [Errno 121] Remote I/O error when the Arduino isn't
    responding) was being swallowed by a catch-all except: pass, so a
    completely dead watcher never raised the alarm/PagerDuty/UI banner -
    the most dangerous case was the silent one. Now it debounces, retries
    reset, and alarms like any other fault.
    - /api gains a "resume" command so a stopped firing can be resumed
    programmatically (mirrors the control-socket resume).
    [kiln-controller.py]
2026-06-27 Keep the control thread alive (fix wedge on Stop)
    The oven control thread could die from an unhandled exception, after
    which Start/Resume silently do nothing (and, worse, the over-temp checks
    stop running) until a service restart. Observed in production: pressing
    Stop races reset() setting absolute_start_time = 0 (int) while the thread
    is mid-heat_then_cool, so its log line computed `int - datetime` and
    raised TypeError, killing the thread.
    - Wrap the per-tick RUNNING body in try/except so any exception is logged
    and the control thread keeps running (it re-evaluates state next pass).
    - Broaden the heat_then_cool periodic-log guard from KeyError to any
    exception so a reset() racing Stop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
2026-06-27 Auto-reconnect websockets + disconnected banner
    The browser opened the four websockets once at page load and never
    recovered them, so a service restart left the page silently stale
    (elements on, but no "Heating" because the status socket was dead and
    nothing recreated it).
    Wrap each socket in a setupXSocket() factory and add a debounced
    scheduleReconnect() that recreates any closed socket every ~2s until the
    service returns. Force a close() on status onerror so a silent error
    still triggers reconnect. Show a persistent amber "Disconnected" banner
    while down; it clears on the next successful status onopen, and the
    status backlog repopulates the live display automatically.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
2026-06-27 Quiet watcher I/O faults while idle
    At startup (and any time the oven is idle) the safety watcher Arduino is
    often unpowered, so reset_watcher()/set_max_temp() hit it over I2C and
    log [Errno 121] Remote I/O error at error level - pure noise, since the
    watcher is only safety-critical during a firing.
    Gate those messages on a new _firing() check: log loudly during a firing
    (a real reset failure matters), debug otherwise. Idle poll faults were
    already silenced; this covers the remaining startup/idle paths.
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2026-06-27 Capture firings as persistent records (firing-tracking Phase 2)
    Answers the long-standing FIXME in ovenWatcher: firings were ephemeral
    (live state only, wiped on Stop/reconnect). Each run is now captured as a
    self-contained, crash-safe bundle under storage/firings/<id>/.
    - lib/firingStore.py: bundle writer. record.json (summary + embedded profile
    snapshot + empty user metadata) and samples.ndjson (one get_state() per line,
    appended live, fsync'd). Atomic record.json writes; summary refreshed on
    segment change and finalize.
    - lib/ovenWatcher.py: open/append/finalize a bundle on the RUNNING edges of the
    watch loop. Terminal status inferred from oven state (ERROR -> error;
    resume_inf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
    [config.py, kiln-controller.py]
2026-06-27 Slim persisted firing samples to graph-essential fields
    Each samples.ndjson line carried the entire get_state() - including the
    upcoming-segments array and the pidstats dict on every sample, plus constants
    (profile name, kwh_rate, currency, resume_*) that belong once in record.json.
    Persist only runtime, temperature, target, state, heat, totaltime, lightly
    rounded (temps to 0.01 deg, below thermocouple resolution). Constant/derived
    data still feeds the record.json summary (cost, segment_count, ...) - it's just
    no longer duplicated per line. runtime + temperature is enough to graph a run
    and to later reconstruct an idealized profile from it.
    The live /status websocket is unchanged: it still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
2026-06-27 Record a firing event timeline (firing-tracking Phase 3)
    Each bundle now carries events.ndjson - a discrete narrative of what happened
    during a run, so the history graph can annotate it rather than showing only a
    temperature curve.
    Events ({ts, type, runtime, detail}):
    - started / completed / aborted / error - lifecycle, emitted by the watcher on
    the RUNNING edges.
    - hold / hold_release, advance, segment_target_edit / segment_hold_edit - user
    actions, emitted at the oven method chokepoints (covers /control and /api),
    with old->new for edits and from/to for advance.
    - segment_transition - RAMP<->HOLD / next-segment, detected in the watch loop.
    - power_interruption + resumed - emitted w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
2026-06-27 Add process.log firing backfill importer (firing-tracking Phase 7)
    Pulled Phase 7 forward so the history UI can be built against real firings.
    scripts/import_firings.py reconstructs firing bundles from a pre-tracking
    process.log. The old per-sample log lines are rich (temp/target/heat_on/
    heat_off/run_time/total_time), so backfilled firings get real curves. The
    importer drops noise (empty/refused/service-restart segments), stitches
    consecutive same-profile segments within --gap-min into one firing (a physical
    firing is often fragmented across crash/restart segments), re-bases each
    sample's runtime to elapsed wall-seconds from the firing start (fragments
    restart run_time at 0, which would fo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
2026-06-27 Add firing history view to the dashboard (firing-tracking Phase 5)
    A History view in the browser dashboard, fed by the /api/firings read API.
    - index.html: a History toggle in the header; live content wrapped in #live_view
    and a new #history_view (list rail + detail). #history deep-link + back to live.
    - picoreflow.css: history styles, scoped under #history_view so they can't
    collide with the live dashboard's .panel/.card/.tooltip. Reuses the existing
    :root design tokens.
    - picoreflow.js: list (sorted by firing date) + detail render. Planned-vs-actual
    Canvas graph (area-filled actual line, faint grid, hover crosshair/tooltip),
    event pins + red interruption bands, and an event time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
2026-06-28 History view: single toggle button + mobile master-detail
    - Replace the separate History button + in-page "< Live Dashboard" link with one
    header button that toggles label/action (History <-> Live Dashboard) and stays
    in the same place.
    - Mobile: master-detail instead of both panes at once. The list shows full-width;
    tapping a firing opens its detail (full-width, with an "All firings" back
    button); desktop keeps the two-pane layout. Removes the horizontal filmstrip
    rail (which forced left/right scrolling) and the side-by-side cramming.
    Verified at a true 390px viewport (CDP device emulation): no horizontal overflow
    on either the list or detail screen; desktop two-pane unchanged.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
2026-06-28 Group the History/Live toggle with the controller name
    The button was floated to the far right of its own full-width header strip — a
    stranded right-hand column on desktop and a wasteful tall strip on mobile. Make
    #controller_header a compact flex row so the toggle sits right next to the
    controller name on all widths.
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2026-06-28 Live firing detail, photos-as-moments, printable report (round 2)
    Brings the rich history detail to the in-progress firing and makes photos
    first-class, plus layout tidy-ups and a printable report.
    - Live unified detail: ovenWatcher broadcasts firing_id on /status; while a
    firing runs the dashboard shows the same detail view (annotated canvas graph +
    live timeline + editable notes) for that firing, polling /api/firings/<id>
    every ~5s. flot is now only the idle profile preview/editor.
    - Segments behind Edit: the live segment editor no longer auto-shows; an
    "Edit schedule" toggle reveals it, table-driven (tap a row to edit
    target/hold; SET_SEGMENT_* over /control).
    - Photos as momen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
    [kiln-controller.py]
2026-06-28 History: stop the graph nudging when an event is selected
    The selected-event caption includes a taller "clear" button than the default
    tip text, so swapping it grew the caption ~4px and pushed the graph down. Pin
    the caption to a fixed 34px height so both states are identical and the graph
    stays put.
2026-06-28 Remove debug print() of the websocket backlog (gevent stall)
    add_observer printed the entire sample backlog (thousands of points during a
    firing) to stdout/journald on every /status websocket (re)connect. Without
    monkey-patching, that synchronous write briefly stalls the gevent server, so a
    connect storm froze the UI and could hang a page mid-load. Drop the prints.
2026-06-29 History/live polish: sorted profiles, MRU, merged card, Edit-schedule, live stats
    - Profile dropdown now sorts case-insensitively (the profiles array is sorted on
    receipt; option indices stay consistent).
    - Recent-firings (MRU) quick pick: the last 7 distinct profiles you've fired show
    as one-tap chips in the idle view (loadMru, refreshed when a firing ends).
    - During a firing, drop the Max temp / Peak target / Duration strip from the live
    detail (it's already in the top status cards); history still shows it.
    - Merge the graph and the timeline into one white card separated by a gray rule
    (replaces the two-card .lower split); notes are their own card.
    - "Edit schedule" now actually to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
2026-06-29 Perf: offload history file I/O to gevent threadpool; lighter live poll
    Keep the gevent web event loop responsive during big firing-history
    reads/writes without monkey-patching (the control loop and watcher stay
    real OS threads).
    - kiln-controller.py: add _io() helper wrapping blocking filesystem
    handlers (list_firings, get_firing, add_photo, delete_firing) in
    gevent's threadpool so a large read can't stall websockets/other
    requests.
    - firingStore.get_firing: add include_samples; GET /api/firings/<id>
    ?samples=0 skips the (large) samples.ndjson read entirely.
    - picoreflow.js: live detail fetches samples once on open to seed the
    curve (seedLiveCurve), then polls ?samples=0 every 12s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
    [kiln-controller.py]
2026-07-18 Capture Bookworm SD-card rebuild: setup script, systemd unit, docs
    - scripts/kiln-firstsetup.sh: post-boot setup fixed for Bookworm
    (/boot/firmware path, apt install curl, enable I2C+SPI, install unit
    from repo, correct authorized_keys path)
    - lib/init/kiln-controller.service: /home/pi -> /home/brian, add
    network-online target + Restart=on-failure
    - docs/rebuild-sd-card.md: Bookworm rebuild gotchas + full procedure
    - docs/remote-access-cloudflare.md: tunnel UUID -> 35f0b8e1...
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2026-07-19 Fix reconnect re-tracing the live actual curve from the origin
    On a /status websocket reconnect the server resends a backlog message
    with the entire firing log. The handler pushed those points onto
    graph.live.data, which already held the accumulated live-stream points,
    so the actual curve ran to the current point and then jumped back to
    runtime 0 and re-traced the whole firing (the spurious line to the start
    plus the fan of re-drawn ramps). A page refresh worked only because the
    buffer starts empty.
    Replace graph.live.data with the backlog instead of appending, guard the
    flot replot behind a visibility check (replotting the hidden container
    throws mid-firing), and rebuild+redraw the live-de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
2026-07-19 Fix disconnected banner sticking when idle sockets bounce
    The banner was shown by scheduleReconnect(), called from all four
    sockets' onclose, but cleared only by ws_status.onopen. The config/
    control/storage sockets go idle after their initial GET and get dropped
    by the Cloudflare tunnel's websocket idle timeout; reopening them never
    cleared the banner (only status.onopen does, and status never closed),
    so it stuck on while the live display kept updating.
    Drive the banner solely from the status socket (the live heartbeat):
    scheduleReconnect() no longer touches it, and ws_status.onclose sets
    disconnected itself. Idle drops on the other sockets now reconnect
    silently.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
2026-07-20 Eliminate two-screen flash on dashboard refresh
    On refresh the flot preview panel was visible by default, so it was
    painted before the code knew the firing state: first with the default
    dropdown profile, then with the current firing's old green/red curve
    (driven by the initial stateless "backlog" websocket message), and only
    then did the view switch to the new live detail. Two wrong screens
    flashed before the right one.
    Hide the flot panel by default and reveal it only once a real /status
    message tells us the state:
    - index.html: the .panel is display:none by default.
    - updateProfile and the control socket guard $.plot on #graph_container
    visibility (matching the backlog/RUNNING handlers)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
2026-07-20 Graph hover: show wall-clock time; make the future/planned curve inspectable
    The crosshair snapped to the nearest actual sample and bailed once there
    were none, so the not-yet-fired portion of the schedule couldn't be
    inspected. It now tracks the cursor freely across the full x range,
    interpolating the planned curve everywhere, so any future point shows its
    planned temp and the clock time it will happen. The marker rides the actual
    curve where data exists (orange) and the planned curve in the future (blue);
    "Actual" drops from the tooltip past the live edge.
    The tooltip title now leads with wall-clock time ("6:42 PM · 37:01
    elapsed", with a day tag past midnight) when a start time is known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
2026-07-20 Firing report timeline: graph-style day/date labels, richer segments, photo bullets, print-safe icons
    - Timeline rows now mirror the graph's labeling: a day/date divider when the
    calendar day shifts, plus wall-clock time over elapsed time.
    - segment_transition rows show ramp rate + destination temp, or hold temp +
    duration, derived from the profile (also used in the graph's selection caption).
    - The photo itself is the bullet in the icon column (centered so its larger size
    overflows into the gaps rather than widening the layout).
    - Segment/photo markers drop the gray circle; event icons emit inline !important
    fill + white glyph so they survive Bootstrap's print reset in index.html, w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
2026-07-20 Detect expired Cloudflare Access and prompt re-login
    A dropped status socket can mean the backend restarted or the Access
    session expired, but a failed WS handshake hides its HTTP status. On
    disconnect, probe /api/stats (whose status we can read): 401/403/redirect
    swaps the generic "reconnecting" banner for an actionable "Session
    expired — re-login" banner; 200 keeps the reconnect banner.
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
